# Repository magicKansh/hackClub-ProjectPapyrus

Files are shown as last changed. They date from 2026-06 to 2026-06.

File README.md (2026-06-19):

# Project Papyrus

*A public repo of my work for Hack Club: Fallout! Subject to various updates. This github is meant to be paired with the neccessary Arduino hardware that is the bulk of the project.*

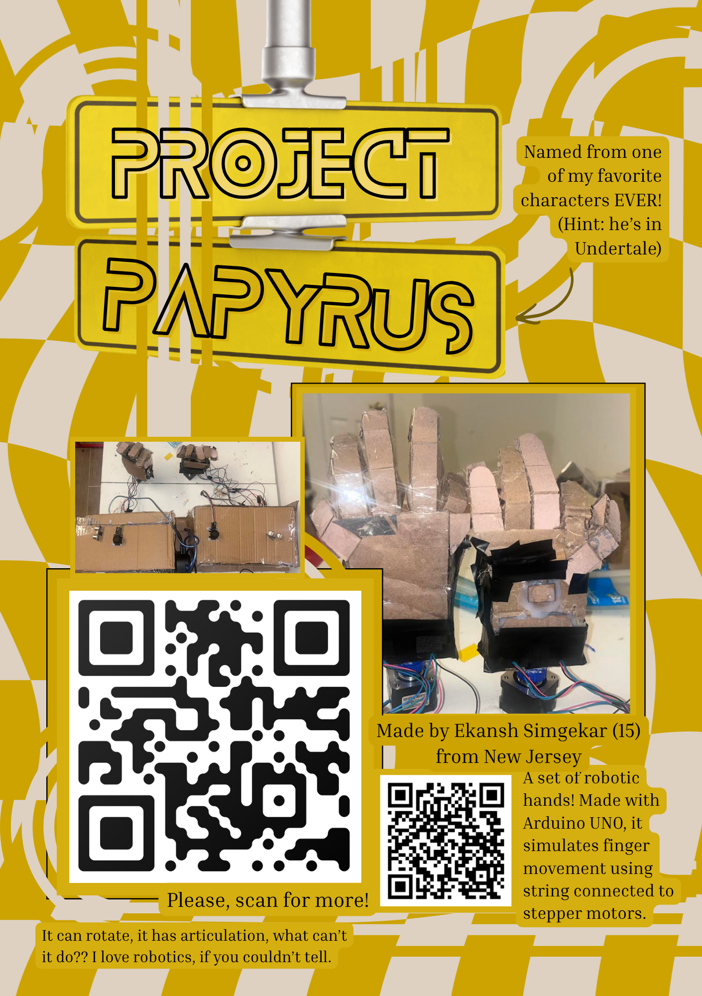
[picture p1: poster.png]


## About It:

Hello! Welcome to my most ambitious project of my technological career yet! This project, named after a certain character from a video game, was at first meant to be a whole robot that I could control with a mask. However, due to time and money constraints (and for the sake of Fallout) I had to shorten it down to two wearable arms and a mask. Recently, I noticed a vital flaw in my design that caused me to scrap a good chunk of it. After many modifications, the project is done as two controllable hands with ultrasonic sensors and joysticks. The joystick controlls the fingers and the rotational movement, being able to fully form a fist or hand gestures with its controls. It utlizes strings to control the fingers, with a stepper motor moving the strings back and forth to simulate movement. I am quite proud of this unique way it simulates a real life human hand, as I haven't seen it done before. Holding the joystick down rotates the hand and moving the left/right (or up/down) moves it clockwise/counterclockwise. I decided to make this as a evolution of a previous Arduino experiment I made, using servos instead for a hand. However, that only had one hand that had little finger movement with no rotation. I plan to update this with a whole wearable arm like I tried previously, but for now please look more into my project below!

---

## Wiring:

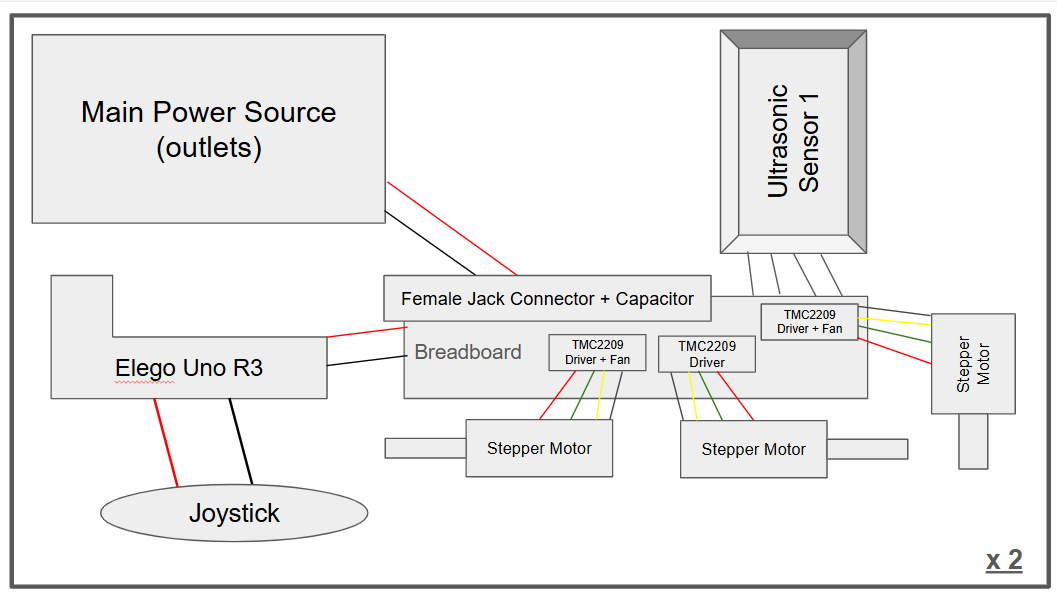
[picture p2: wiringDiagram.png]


Above is a wiring diagram that will help to understand the components used! The entire thing is centered around the arduino circutry, using breadboards, NEMA-17 stepper motors, and ultrasonic sensors. My computer science teacher suggested keeping all of the stepper motors centralized, to avoid excess power usage, coming at the cost of only being able to use one motor at a time (to avoid burnout). The stepper motors are regulated by the drivers and kept cool with the fans. Capacitors store power in the case of fluculation. Two stepper motors are used for the movement of fingers and one is used at the bottom for hand rotational movement. Go Johnny Go!

---

## CAD Design:

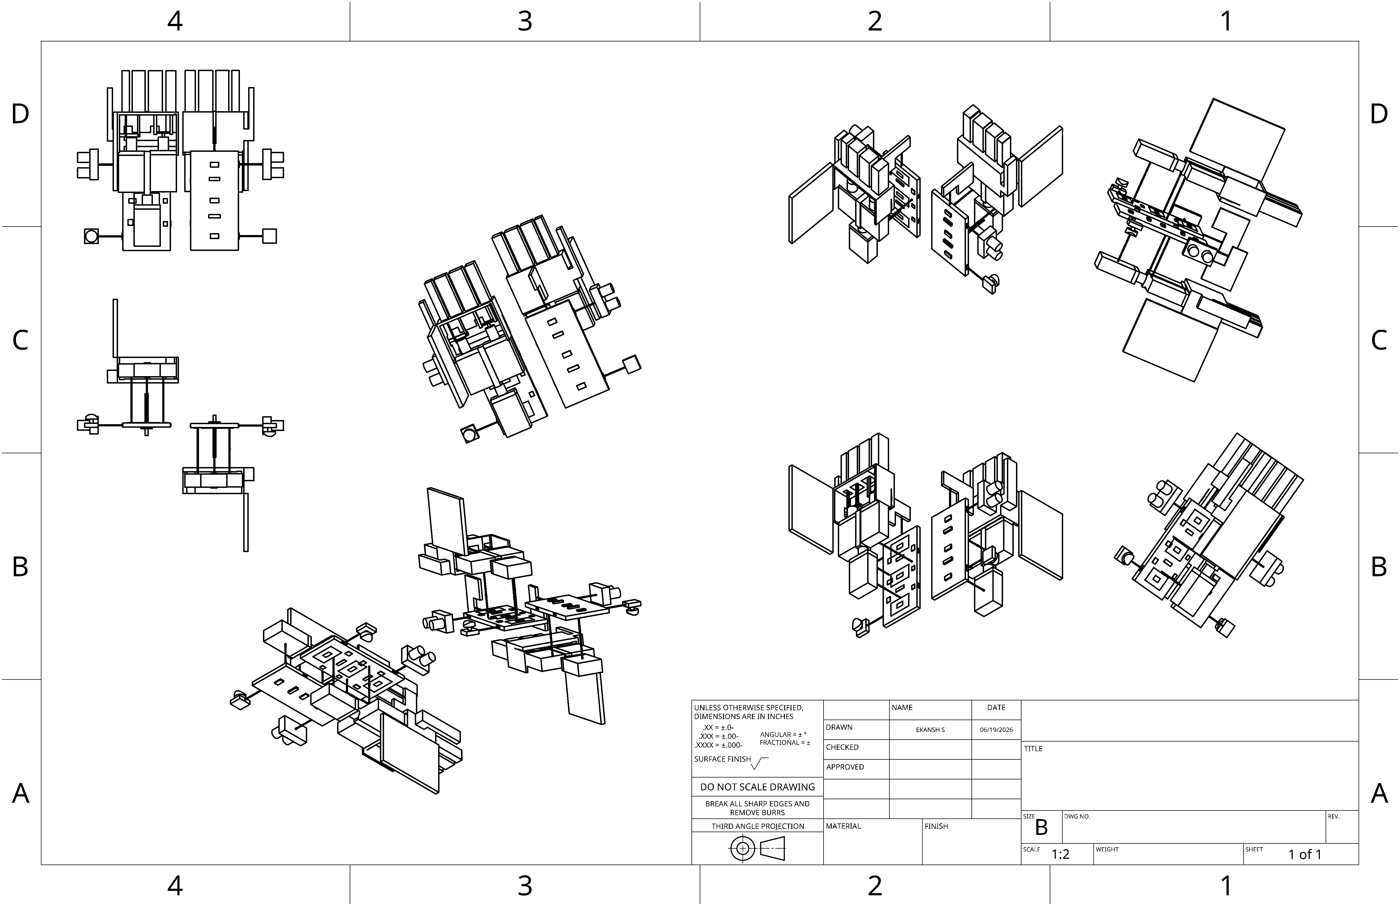
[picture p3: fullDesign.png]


Feel free to download the individual pieces from this github repo, but this is a 3D model of my innovation! I still feel that I am a beginner in onshape, but this project helped further my skills in this area. It's so nice to see that time and effort that is put into a project can be rewarded. Components are attached by industrial grade glue, used in my own robotics team to attach circutry. The bill of materials can be found [here.](BOM.csv) A link to my onshape can be found here: https://cad.onshape.com/documents/a3976ec1db42c092d0e7bb52/w/d015cfe781e8d86ab63d2d9d/e/b42a30408853c60ea30fe035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

---

## Build Guide:

This system utlizes two arduinos, Arduino A, for the ultrasonic and joystick, and Arduino B, for the stepper motors. Since putting all of the wiring onto one arduino wasn't possible, with voltage and wiring space, I utlized six signal wires to provide arduino B information from arduino A about distance and joystick behavior. Based on that info, Arduino B would drive three NEMA - 17 motors based on the signals. This structure allowed me to make the behavior of my innovation look like:
- Joystick goes UP, Motor A spins clockwise.
- Joystick goes DOWN, Motor A spins counterclockwise.
- Joystick goes LEFT, Motor B spins clockwise.
- Joystick goes RIGHT, Motor B spins counterclockwise.
- Joystick gets pressed, Motor C spins.

The code specifies that only one motor should move at a time, and the joystick input takes priority. When an object is detected 20 cm away, all three motors run a full forward then reverse sequence one after another (ABC order).

### 1. Parts List

| Part | Qty | Notes |
|---|---|---|
| Arduino Uno (or Uno-compatible board) | 2 | One labeled "A" (sensor board), one "B" (motor board). |
| NEMA 17 stepper motor | 3 | Standard 1.8°/step (200 steps/rev) bipolar motor |
| TMC2209 stepper driver module | 3 | One per motor. STEP/DIR/EN interface used here (no UART configuration) |
| HC-SR04 ultrasonic distance sensor | 1 | |
| Analog joystick module (2-axis + button) | 1 | VRX, VRY, SW, VCC, GND pinout |
| 12 V DC power supply | 1 | Powers motor coils (VMOT) only — sized for your motors' rated current x3 |
| 5–9 V regulated supply or battery pack for each Arduino | 2 | — a single small 9V alkaline battery is **not recommended** |
| Breadboard(s) and jumper wires | — | Solid-core wires or well-seated jumpers recommended for reliability |
| Common ground bus / rail | — | All grounds (both Arduinos, both power supplies, all drivers, sensor, joystick) must tie to one shared point |

---

### 2. Arduino A — Sensor and Joystick Wiring

**Ultrasonic Sensor (HC-SR04)**

| HC-SR04 Pin | Arduino A Pin |
|---|---|
| VCC | 5V |
| GND | GND |
| Trig | D10 |
| Echo | D5 |

**Joystick Module (powered at 3.3 V)**

| Joystick Pin | Arduino A Pin |
|---|---|
| VCC | 3.3V |
| GND | GND |
| VRX | A0 |
| VRY | A1 |
| SW | D8 |

**Outputs from Arduino A → Arduino B**

| Signal | Arduino A Pin | Purpose |
|---|---|---|
| sigA | D2 | Motor A move flag (HIGH = move) |
| sigA_dir | D6 | Motor A direction (HIGH = UP/CW, LOW = DOWN/CCW) |
| sigB | D3 | Motor B move flag (HIGH = move) |
| sigB_dir | D7 | Motor B direction (HIGH = LEFT/CW, LOW = RIGHT/CCW) |
| sigC | D4 | Motor C move flag (HIGH = button pressed) |
| sigU | D9 | Ultrasonic trigger pulse (HIGH = object detected) |
| GND | GND | Shared ground — **critical**, see Section 6 |

---

### 3. Arduino B — Motor Board Wiring

**Inputs from Arduino A**

| Signal | Arduino B Pin | From Arduino A Pin |
|---|---|---|
| sigA | A0 | D2 |
| sigA_dir | A1 | D6 |
| sigB | D10 | D3 |
| sigB_dir | A2 | D7 |
| sigC | D5 | D4 |
| sigU | D9 | D9 |
| GND | GND | GND |

> **Do not use Arduino B's pin 1 (TX) or pin 0 (RX) for any signal wire.**
> Those pins connect to the onboard USB-to-serial chip. A signal wire sharing
> that pin will corrupt Serial communication and can cause the board to behave
> as if it's resetting. This guide's pinout avoids them entirely.

**TMC2209 Driver → Motor Wiring**

| Motor | STEP | DIR | EN | Driver power |
|---|---|---|---|---|
| Motor A | D11 | D12 | D13 | VIO → 5V, VMOT → 12V supply, GND → common ground |
| Motor B | D6 | D7 | D8 | VIO → 5V, VMOT → 12V supply, GND → common ground |
| Motor C | D3 | D2 | D4 | VIO → 5V, VMOT → 12V supply, GND → common ground |

EN is active-LOW on the TMC2209 — the code holds all three EN pins LOW at startup to keep the drivers enabled.

---

### 4. Step-by-Step Assembly

1. **Build the ground network first.** Connect a ground rail/bus that ties together: Arduino A GND, Arduino B GND, the 12V supply's negative terminal, all three TMC2209 GND pins, the joystick GND, and the ultrasonic sensor GND. Use more than one wire between Arduino A and Arduino B's grounds if possible — this single network is the most common source of problems in this build.

2. **Wire the ultrasonic sensor and joystick to Arduino A** per the tables in Section 2.

3. **Wire the three TMC2209 drivers to Arduino B** per Section 3. Double check STEP/DIR/EN per motor — these are easy to cross between motors.

4. **Connect VMOT on all three TMC2209 boards to the 12V supply**, separate from the Arduinos' own power. Do not power the motors from the same small battery powering Arduino logic.

5. **Run the six signal wires + ground wire from Arduino A to Arduino B** exactly per the table in Section 3. Press connections in firmly; loose breadboard contacts are a common cause of intermittent motor behavior.

6. **Upload the code** (Section 5) — Arduino A's sketch to board A, Arduino B's sketch to board B. Leave both connected to USB for first testing.

7. **Test on USB power first.** Confirm joystick directions move the correct motor the correct way, the button moves Motor C, and waving a hand within 20 cm of the ultrasonic sensor triggers the full sequence. In my experience, it only worked on USB power, 9v batteries were NOT enough.

---

### 5. Code

**Arduino A — Sensor & Joystick Controller**

```cpp
// ============================================================
//  ARDUINO A — Sensor & Joystick Controller
// ============================================================
//
//  WIRING — Arduino A:
//    Ultrasonic HC-SR04:  Trig -> pin 10,  Echo -> pin 5
//                         VCC  -> 5V,      GND  -> GND
//    Joystick (3.3V):     VRX  -> A0,      VRY  -> A1
//                         SW   -> pin 8,   VCC  -> 3.3V
//                         GND  -> GND
//
//  WIRING — Arduino A -> Arduino B (6 signal wires + GND):
//    A pin 2  -> B pin A0   (Motor A move flag)
//    A pin 6  -> B pin A1   (Motor A direction)
//    A pin 3  -> B pin 10   (Motor B move flag)
//    A pin 7  -> B pin A2   (Motor B direction)
//    A pin 4  -> B pin 5    (Motor C / button)
//    A pin 9  -> B pin 9    (Ultrasonic trigger)
//    A GND    -> B GND
//
//  BEHAVIOUR:
//    Joystick UP    -> Motor A clockwise
//    Joystick DOWN  -> Motor A counterclockwise
//    Joystick LEFT  -> Motor B clockwise
//    Joystick RIGHT -> Motor B counterclockwise
//    Joystick button -> Motor C
//    Object < 20cm (no joystick input) -> ultrasonic sequence on B
// ============================================================

const int trigPin = 10;
const int echoPin = 5;

const int vrxPin = A0;
const int vryPin = A1;
const int swPin  = 8;

const int sigA     = 2;  // Motor A move flag
const int sigA_dir = 6;  // Motor A direction: HIGH = UP (CW), LOW = DOWN (CCW)
const int sigB     = 3;  // Motor B move flag
const int sigB_dir = 7;  // Motor B direction: HIGH = LEFT (CW), LOW = RIGHT (CCW)
const int sigC     = 4;  // Motor C (button)
const int sigU     = 9;  // Ultrasonic trigger

// Joystick dead-zone thresholds.
// Joystick is 3.3V powered -> analogRead range is roughly 0-675, center ~338.
// Run the calibration sketch in Section 8 if your readings differ.
const int JOY_LOW  = 250;
const int JOY_HIGH = 450;

long readUltrasonic() {
  digitalWrite(trigPin, LOW);
  delayMicroseconds(2);
  digitalWrite(trigPin, HIGH);
  delayMicroseconds(10);
  digitalWrite(trigPin, LOW);
  long duration = pulseIn(echoPin, HIGH, 30000); // 30ms timeout
  if (duration == 0) return 999;                  // nothing detected
  return duration * 0.034 / 2;                    // convert to cm
}

void setup() {
  pinMode(trigPin, OUTPUT);
  pinMode(echoPin, INPUT);
  pinMode(swPin, INPUT_PULLUP);

  pinMode(sigA, OUTPUT);
  pinMode(sigA_dir, OUTPUT);
  pinMode(sigB, OUTPUT);
  pinMode(sigB_dir, OUTPUT);
  pinMode(sigC, OUTPUT);
  pinMode(sigU, OUTPUT);

  digitalWrite(sigA, LOW);
  digitalWrite(sigA_dir, LOW);
  digitalWrite(sigB, LOW);
  digitalWrite(sigB_dir, LOW);
  digitalWrite(sigC, LOW);
  digitalWrite(sigU, LOW);
}

void loop() {
  // --- Ultrasonic trigger ---
  long dist = readUltrasonic();
  if (dist > 0 && dist < 20) {
    digitalWrite(sigU, HIGH);
    delay(100);
    digitalWrite(sigU, LOW);
  }

  // --- Joystick read ---
  int xVal  = analogRead(vrxPin);
  int yVal  = analogRead(vryPin);
  int swVal = digitalRead(swPin);

  bool up    = (yVal < JOY_LOW);
  bool down  = (yVal > JOY_HIGH);
  bool left  = (xVal < JOY_LOW);
  bool right = (xVal > JOY_HIGH);

  digitalWrite(sigA, (up || down) ? HIGH : LOW);
  digitalWrite(sigA_dir, up ? HIGH : LOW);

  digitalWrite(sigB, (left || right) ? HIGH : LOW);
  digitalWrite(sigB_dir, left ? HIGH : LOW);

  digitalWrite(sigC, (swVal == LOW) ? HIGH : LOW);

  delay(20); // ~50Hz polling rate
}
```

**Arduino B — Motor Controller**

```cpp
// ============================================================
//  ARDUINO B — Motor Controller (3x NEMA 17 via TMC2209)
// ============================================================
//
//  WIRING — Signals from Arduino A (6 signal wires + GND):
//    B pin A0  <- A pin 2   (Motor A move flag)
//    B pin A1  <- A pin 6   (Motor A direction)
//    B pin 10  <- A pin 3   (Motor B move flag)
//    B pin A2  <- A pin 7   (Motor B direction)
//    B pin 5   <- A pin 4   (Motor C / button)
//    B pin 9   <- A pin 9   (Ultrasonic trigger)
//    B GND     <- A GND
//
//  Motor A driver:  STEP -> 11, DIR -> 12, EN -> 13
//  Motor B driver:  STEP -> 6,  DIR -> 7,  EN -> 8
//  Motor C driver:  STEP -> 3,  DIR -> 2,  EN -> 4
//  All drivers: VIO -> 5V (logic), VMOT -> 12V external supply, GND -> common
// ============================================================

const int sigA     = A0;
const int sigA_dir = A1;
const int sigB     = 10;
const int sigB_dir = A2;
const int sigC     = 5;
const int sigU     = 9;

const int stepA = 11, dirA = 12, enA = 13;
const int stepB = 6,  dirB = 7,  enB = 8;
const int stepC = 3,  dirC = 2,  enC = 4;

// --- Joystick-tap speed per motor (microseconds per half-pulse, lower = faster) ---
const int STEP_DELAY_A   = 12000; // Motor A — slow
const int STEP_DELAY_B   = 1000;  // Motor B — fast
const int STEP_DELAY_C   = 1000;  // Motor C — fast
const int JOYSTICK_STEPS = 3;     // steps fired per joystick poll

// --- Acceleration ramp settings for the ultrasonic sequence ---
// Long moves ramp from START_DELAY (slow/high torque) down to each
// motor's cruise speed (MIN_DELAY_x) and back up before stopping —
// this prevents stalling against a stationary/weighted load.
const int START_DELAY = 3000;
const int MIN_DELAY_A = 500;
const int MIN_DELAY_B = 200;
const int MIN_DELAY_C = 200;
const int RAMP_STEPS  = 100;

void stepMotor(int stepPin, int steps, int delayMicros) {
  for (int i = 0; i < steps; i++) {
    digitalWrite(stepPin, HIGH);
    delayMicroseconds(delayMicros);
    digitalWrite(stepPin, LOW);
    delayMicroseconds(delayMicros);
  }
}

void stepMotorRamped(int stepPin, int totalSteps, int minDelay) {
  for (int i = 0; i < totalSteps; i++) {
    int delayMicros;
    if (i < RAMP_STEPS) {
      delayMicros = START_DELAY - ((START_DELAY - minDelay) * i / RAMP_STEPS);
    } else if (i >= totalSteps - RAMP_STEPS) {
      int stepsFromEnd = totalSteps - i;
      delayMicros = START_DELAY - ((START_DELAY - minDelay) * stepsFromEnd / RAMP_STEPS);
    } else {
      delayMicros = minDelay;
    }
    digitalWrite(stepPin, HIGH);
    delayMicroseconds(delayMicros);
    digitalWrite(stepPin, LOW);
    delayMicroseconds(delayMicros);
  }
}

// --- Debounce: majority-vote filter to reject brief noise spikes on
//     the signal lines (caused by motor switching noise on shared ground) ---
const int SAMPLES = 10;
const int SAMPLE_GAP_US = 50;
const int THRESHOLD = 7; // need at least 7 of 10 samples HIGH to count as active

bool readStable(int pin) {
  int count = 0;
  for (int i = 0; i < SAMPLES; i++) {
    if (digitalRead(pin) == HIGH) count++;
    delayMicroseconds(SAMPLE_GAP_US);
  }
  return count >= THRESHOLD;
}

void setup() {
  pinMode(sigA, INPUT);
  pinMode(sigA_dir, INPUT);
  pinMode(sigB, INPUT);
  pinMode(sigB_dir, INPUT);
  pinMode(sigC, INPUT);
  pinMode(sigU, INPUT);

  pinMode(stepA, OUTPUT); pinMode(dirA, OUTPUT); pinMode(enA, OUTPUT);
  pinMode(stepB, OUTPUT); pinMode(dirB, OUTPUT); pinMode(enB, OUTPUT);
  pinMode(stepC, OUTPUT); pinMode(dirC, OUTPUT); pinMode(enC, OUTPUT);

  // EN is active LOW on TMC2209 -- enable all drivers at startup
  digitalWrite(enA, LOW);
  digitalWrite(enB, LOW);
  digitalWrite(enC, LOW);
}

void loop() {
  bool A = readStable(sigA);
  bool B = readStable(sigB);
  bool C = readStable(sigC);
  bool U = readStable(sigU);

  // === JOYSTICK PRIORITY (one motor at a time) ===
  if (A) {
    bool dirHigh = readStable(sigA_dir);
    digitalWrite(dirA, dirHigh ? HIGH : LOW);
    stepMotor(stepA, JOYSTICK_STEPS, STEP_DELAY_A);
    return;
  }

  if (B) {
    bool dirHigh = readStable(sigB_dir);
    digitalWrite(dirB, dirHigh ? HIGH : LOW);
    stepMotor(stepB, JOYSTICK_STEPS, STEP_DELAY_B);
    return;
  }

  if (C) {
    digitalWrite(dirC, HIGH);
    stepMotor(stepC, JOYSTICK_STEPS, STEP_DELAY_C);
    return;
  }

  // === ULTRASONIC SEQUENCE (only runs if no joystick input active) ===
  if (U) {
    digitalWrite(dirA, HIGH);
    stepMotorRamped(stepA, 1000, MIN_DELAY_A);
    digitalWrite(dirA, LOW);
    stepMotorRamped(stepA, 1000, MIN_DELAY_A);

    digitalWrite(dirB, HIGH);
    stepMotorRamped(stepB, 1000, MIN_DELAY_B);
    digitalWrite(dirB, LOW);
    stepMotorRamped(stepB, 1000, MIN_DELAY_B);

    digitalWrite(dirC, HIGH);
    stepMotorRamped(stepC, 1000, MIN_DELAY_C);
    digitalWrite(dirC, LOW);
    stepMotorRamped(stepC, 1000, MIN_DELAY_C);
  }
}
```

---

### 6. Power Supply Notes

- **Motor power (VMOT) and Arduino logic power must be separate supplies**, joined only by a common ground. Do not power motors from the same battery/supply powering the Arduino's 5V logic.
- **A single small 9V alkaline battery is not a good choice** for Arduino logic power in this build. It has low capacity (~500 mAh) and its voltage sags under load — and switching noise from the TMC2209 drivers coupling back through the shared ground can be enough to brown out or glitch the microcontroller right as motors start moving. A AA battery pack (6-8 cells, regulated) or a small regulated 7-12V supply per Arduino is more reliable.
- **Pin 1 (TX) and pin 0 (RX) on Arduino B are reserved** for the onboard USB-to-serial chip. Avoid routing any project signal through them; this guide's pinout (Section 3) does not use them, freeing them up for `Serial.begin()` debugging whenever Arduino B is connected to USB.

---

### 7. Troubleshooting Quick Reference

| Symptom | Likely cause | Fix |
|---|---|---|
| Only one motor ever moves, even unprompted | A signal pin is floating or noisy | Confirm wiring matches Section 3 exactly; check ground network. |
| Works on USB, fails on battery | Weak/sagging battery, or ground bounce with no USB ground backbone | Use a better-quality supply; add parallel ground wires. |
| "USB device malfunctioned" on plug-in | Damaged USB chip/cable/port from an earlier fault, or driver issue | Try a different cable/port/computer to isolate; reinstall CH340 driver if applicable |
| Upload fails: "programmer is not responding" | Serial Monitor left open blocking the port, or wrong board/port selected | Close Serial Monitor, verify Tools > Board/Port, try a different USB cable |
| Direction (CW/CCW) inconsistent on one axis | Loose connection on that direction wire, or noise not fully filtered | Wiggle-test the wire at both ends while running; reseat or add a parallel wire |
| Motor stalls/buzzes under load instead of turning | Insufficient torque at the speed commanded, or TMC2209 current limit (Vref) too low | Use `stepMotorRamped()` for long moves; check/raise the driver's current limit via its Vref trimpot |

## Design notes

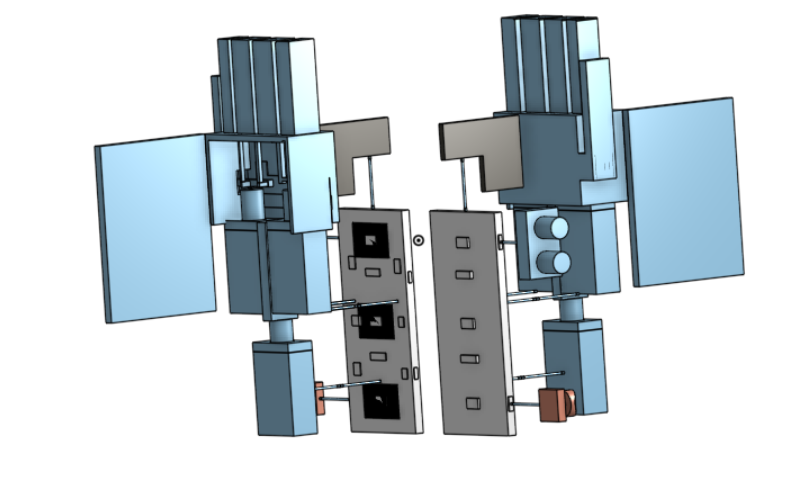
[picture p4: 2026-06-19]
3dmodel.png

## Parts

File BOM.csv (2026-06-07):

Item: |  | Quantity | Link
Stepper Motor |  | 5 | https://www.alibaba.com/product-detail/In-Stock-Nema-17-Series-Stepper_1601591409490.html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
Stepper Motor Addon |  | 5 | https://www.alibaba.com/product-detail/Customizable-OEM-Aluminium-Motor-Shaft-Coupling_1601520888369.html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
Stepper Motor Mount |  | 5 | https://www.alibaba.com/product-detail/42-Steppr-Motor-L-Type-NEMA_1600906641190.html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
TMC2209 Driver |  | 5 | https://www.alibaba.com/product-detail/BIGTREETECH-TMC2209-V1-3-Driver-Module_1601391754682.html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
Capacitors |  | 5 | https://www.amazon.com/10x12-5mm-Electrolytic-Capacitor-Aluminum-Capacitors/dp/B0F8BZVBKF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
Battery |  | 5 | https://www.alibaba.com/product-detail/5V-9V-12V-15V-19V-24V_1601006928195.html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
Ultrasonic Sensors |  | 2 | https://www.alibaba.com/product-detail/Dongheng-HC-SR04-SR04P-Ultrasonic-Sensor_1601517733464.html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
Elego Uno R3 |  | 9 | https://www.alibaba.com/product-detail/Hot-Sale-SET-R3-Development-Board_1601568886149.html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
Wires |  | 240 | https://www.amazon.com/Elegoo-EL-CP-004-Multicolored-Breadboard-arduino/dp/B01EV70C78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
Breadboards |  | 9 | https://www.alibaba.com/product-detail/400-Tie-Points-Solderless-8-5CM_1601199302687.html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
Female Jack Connectors |  | 5 | https://www.amazon.com/LUORNG-Threaded-Connector-Pre-soldered-Waterproof/dp/B09H5L3KN5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
Mini Servos |  | 10 | https://www.alibaba.com/product-detail/Feetech-FS90R-Micro-Servo-360-Degree_1601265788701.html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
Piezo Sensors |  | 5 | https://www.amazon.com/Passive-Resistance-Electronic-Magnetic-Continuous/dp/B0F1KFHSNK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
Joysticks |  | 4 | https://www.alibaba.com/product-detail/YHX-KY-023-Development-Board-Dual_1601767543612.html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
Alligator Clips |  | 2 | https://www.amazon.com/gp/aw/d/B0F7LJQMKH/?aaxitk=aef71756782d792ff3d1f40bc4f21e06&hsa_cr_id=0
Cooling Fan |  | 4 | https://www.alibaba.com/product-detail/AM2010S12H-20mm-12V-DC-Fans-Hydraulic_1601677693603.html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
TOTAL COST: | $149

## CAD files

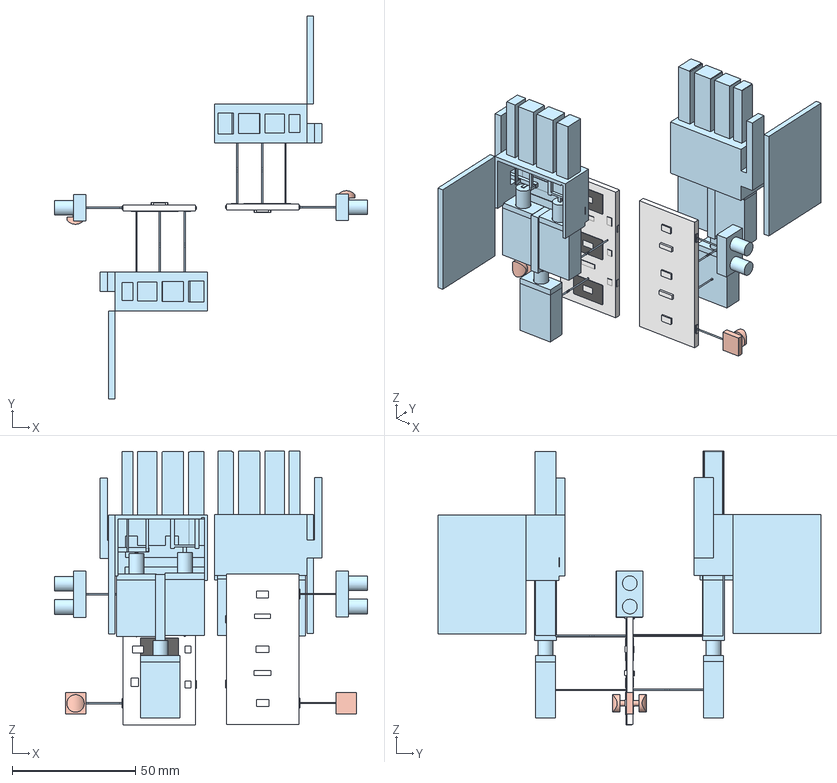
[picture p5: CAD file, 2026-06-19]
cad/Assembly/Hand Assembly.step
127.1 x 155.4 x 111.0 mm

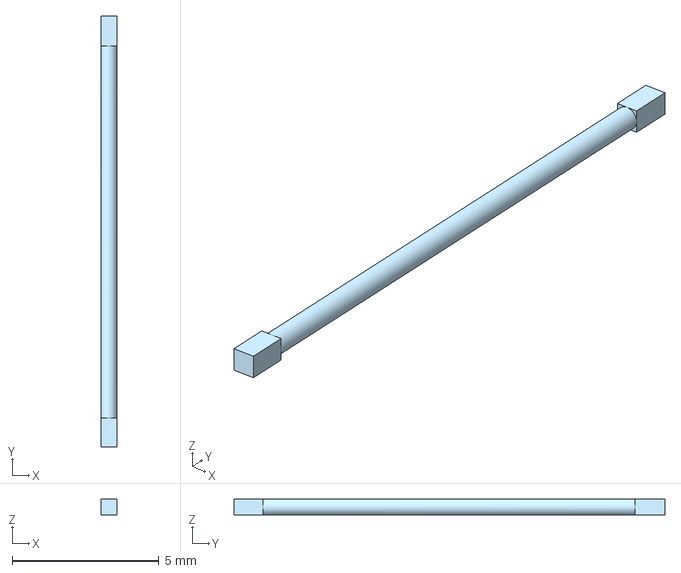
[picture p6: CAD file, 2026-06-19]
cad/Circutry/Wire.step
0.542 x 14.7 x 0.545 mm

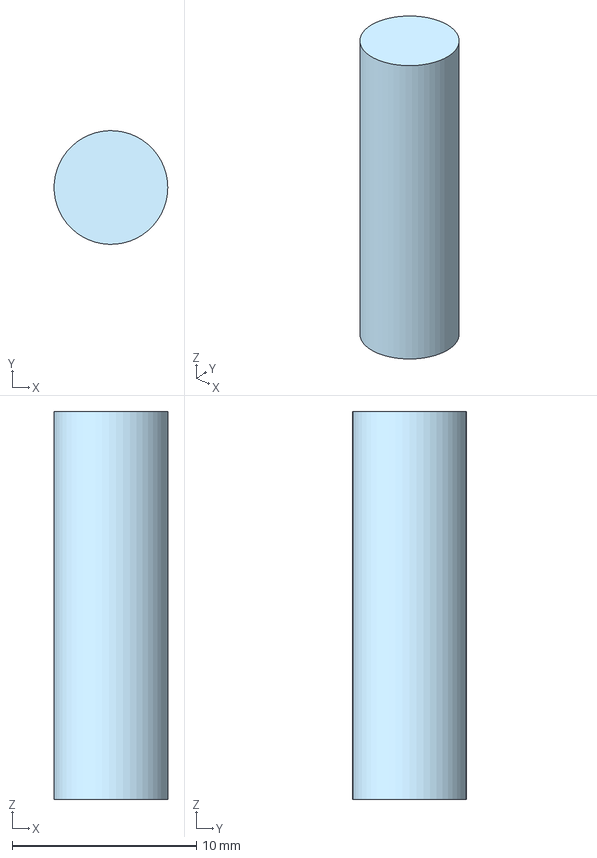
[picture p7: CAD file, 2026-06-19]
cad/Parts/Motor Axle.step
6.16 x 6.16 x 21.0 mm

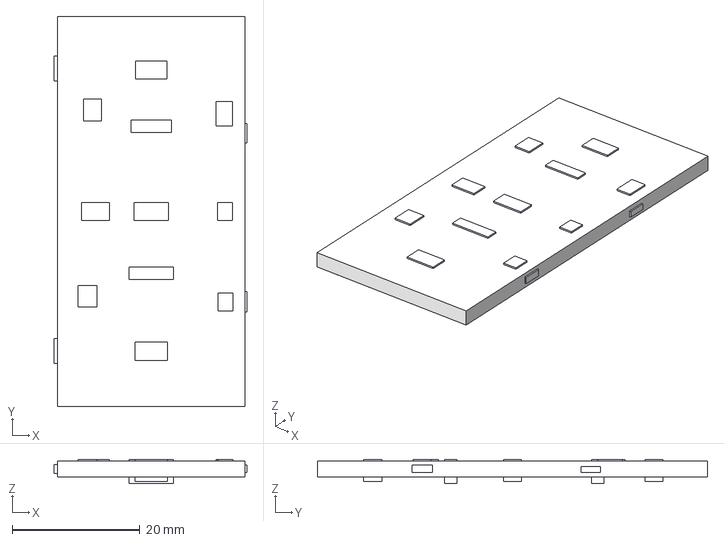
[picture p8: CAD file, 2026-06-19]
cad/Circutry/Breadboard.step
30.1 x 61.0 x 3.81 mm

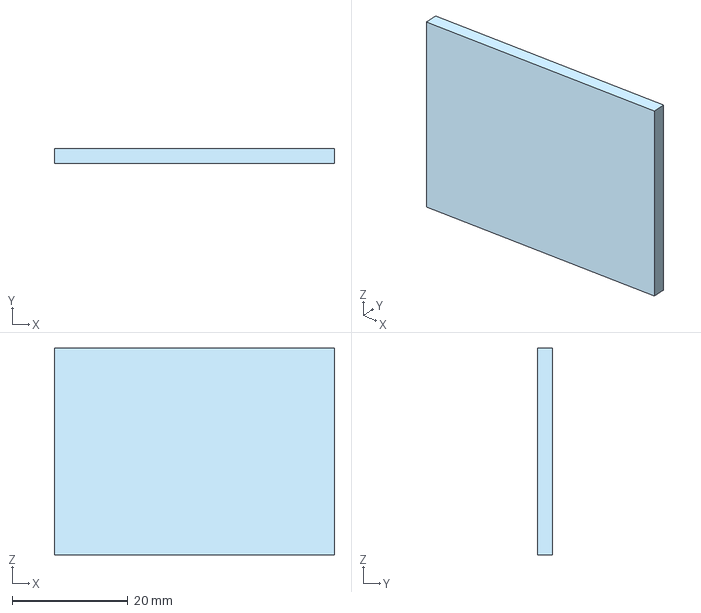
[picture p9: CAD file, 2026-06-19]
cad/Parts/Hand Lid.step
48.4 x 2.54 x 35.7 mm

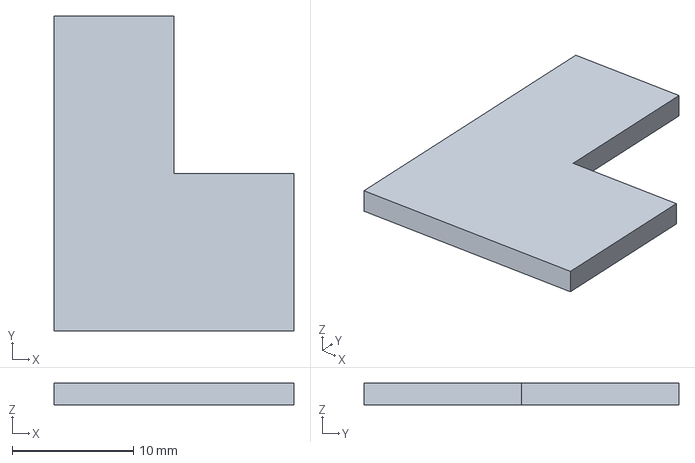
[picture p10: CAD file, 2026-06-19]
cad/Circutry/Arduino Uno.step
19.7 x 25.9 x 1.78 mm

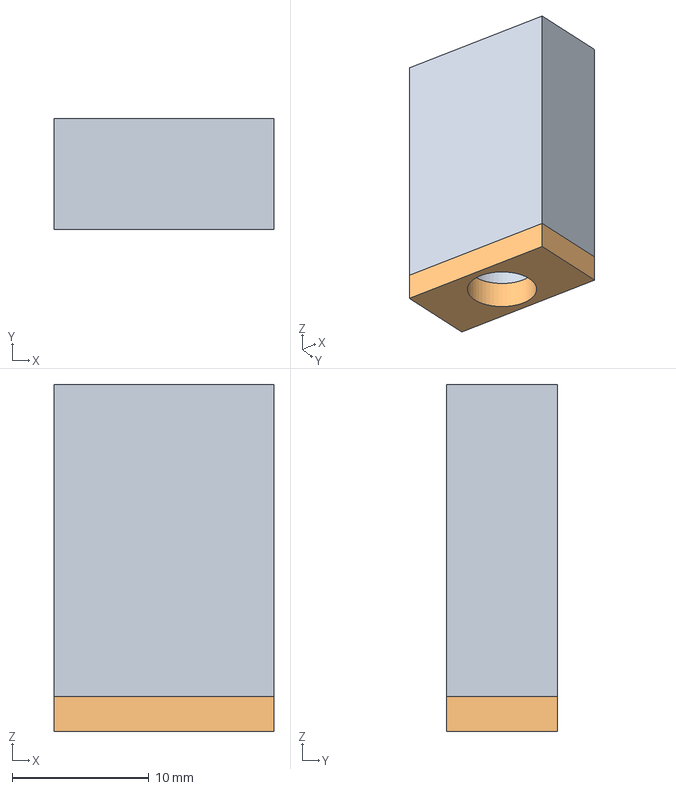
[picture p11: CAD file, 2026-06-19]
cad/Parts/Motor.step
16.1 x 8.12 x 25.4 mm

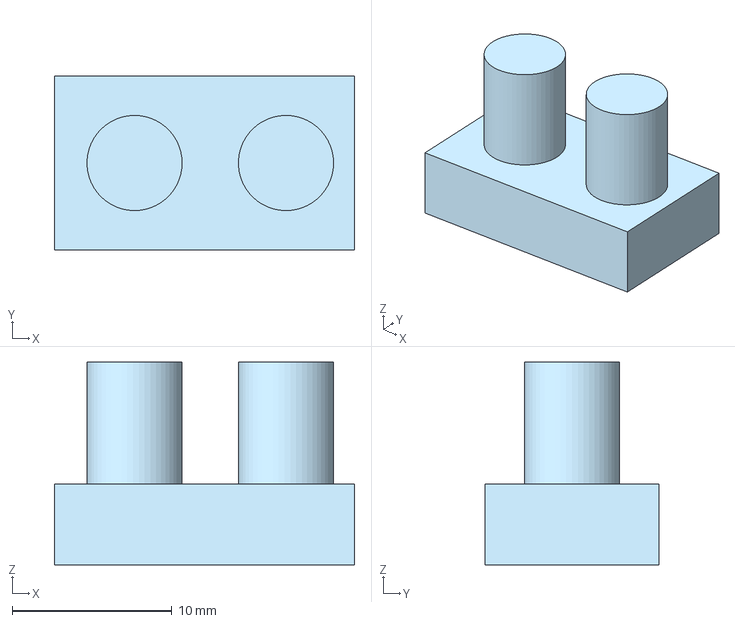
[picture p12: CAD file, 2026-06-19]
cad/Circutry/Ultrasonic Sensor.step
18.8 x 10.9 x 12.7 mm

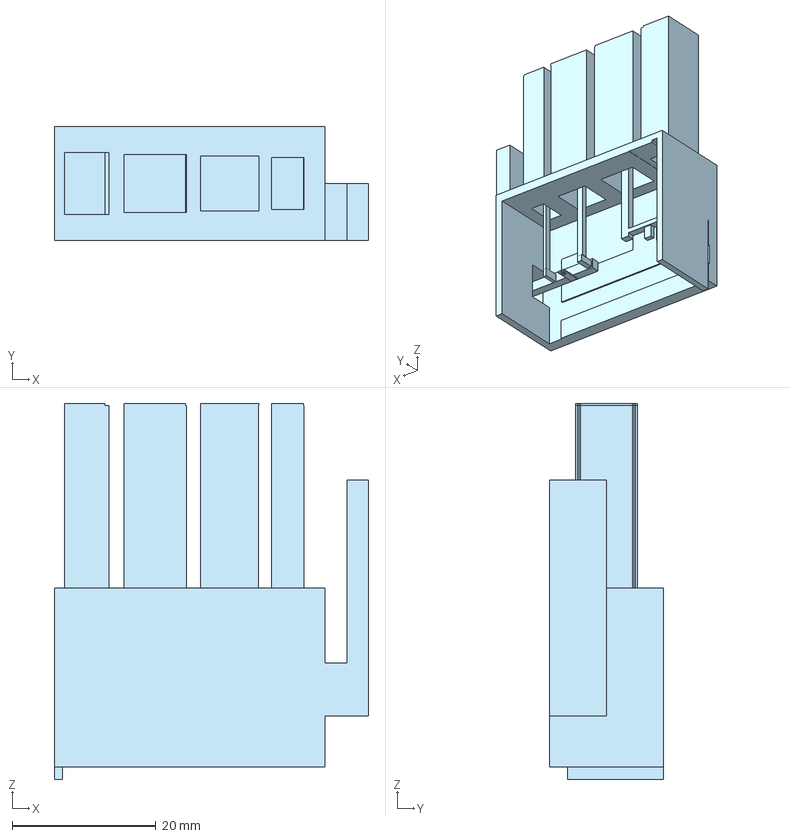
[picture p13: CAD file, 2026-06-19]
cad/Parts/za hando.step
43.7 x 15.8 x 52.2 mm

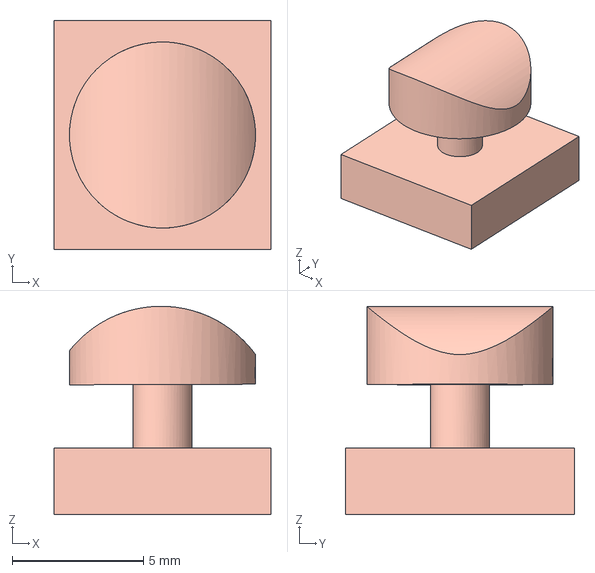
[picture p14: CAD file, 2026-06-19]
cad/Circutry/Joystick.step
8.28 x 8.75 x 7.95 mm

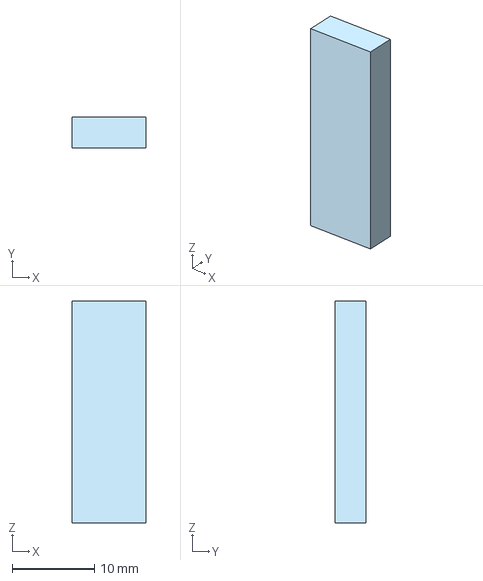
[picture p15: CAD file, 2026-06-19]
cad/Parts/Placeholder Tape.step
8.99 x 3.81 x 27.0 mm

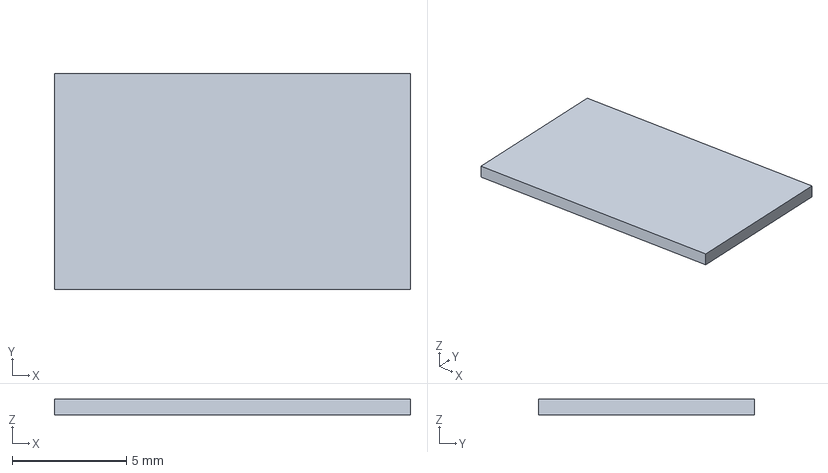
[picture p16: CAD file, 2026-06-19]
cad/Circutry/Driver.step
15.6 x 9.42 x 0.686 mm

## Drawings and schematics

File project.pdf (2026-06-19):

# Project

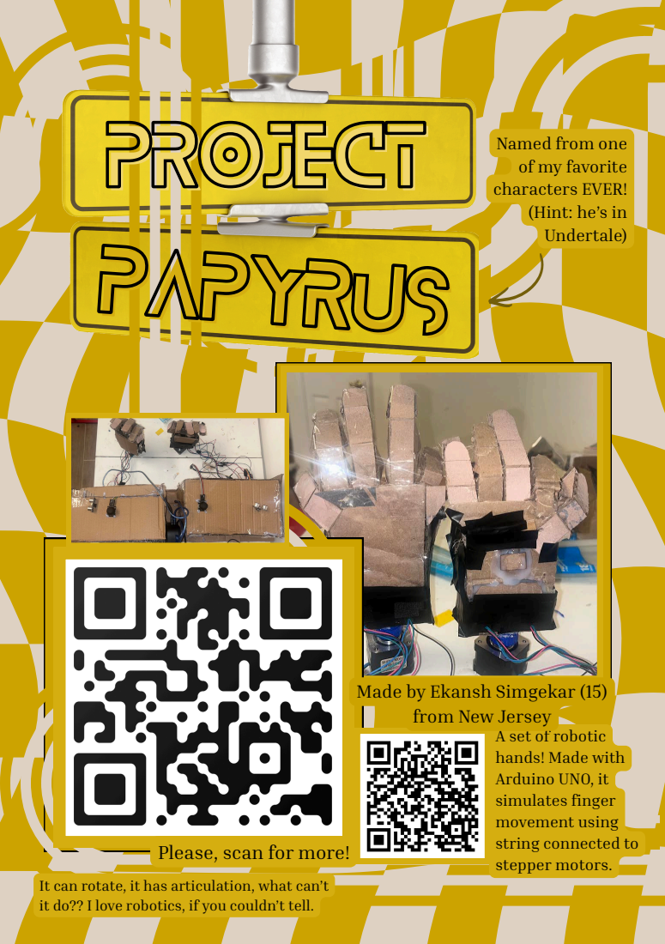
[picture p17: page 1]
Papyrus Papyrus

Named from one
of my favorite
characters EVER!
(Hint: he’s in
Undertale)

Made by Ekansh Simgekar (15)
from New Jersey

A set of robotic
hands! Made with
Arduino UNO, it
simulates finger
movement using
string connected to
stepper motors.

Please, scan for more!

It can rotate, it has articulation, what can’t
it do?? I love robotics, if you couldn’t tell.

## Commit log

2026-04-26 Add motor control setup and loop functions
2026-04-26 Add ultrasonic distance sensing functionality
2026-06-07 Rename Matierials for Hack Club - Sheet1.csv to materials.csv
    [materials.csv]
2026-06-14 Add Arduino A code for sensor and joystick control
2026-06-18 Rename Hand Assembly Drawing 1.png to fulldesign.png
2026-06-18 Fix CAD design image link in README
    Updated image link for CAD design in README.
2026-06-18 Revise README with project updates and corrections
    Updated project description, wiring details, and CAD design information. Corrected terminology and clarified component usage.
2026-06-18 Update motor control and wiring configurations
    Refactor motor control logic and update wiring comments.
2026-06-18 Refactor joystick control for motors and add direction
    Updated wiring and logic for motor direction control based on joystick input.
2026-06-19 Add motorMovementArduino(B).ino file
